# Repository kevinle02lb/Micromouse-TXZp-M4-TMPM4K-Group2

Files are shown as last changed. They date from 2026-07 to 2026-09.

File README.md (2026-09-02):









<div align="center">

# 🐭 Toshiba Micromouse

**Autonomous 16×16 Maze-Solving Robot**  
*Register-level firmware on Arm Cortex-M4*

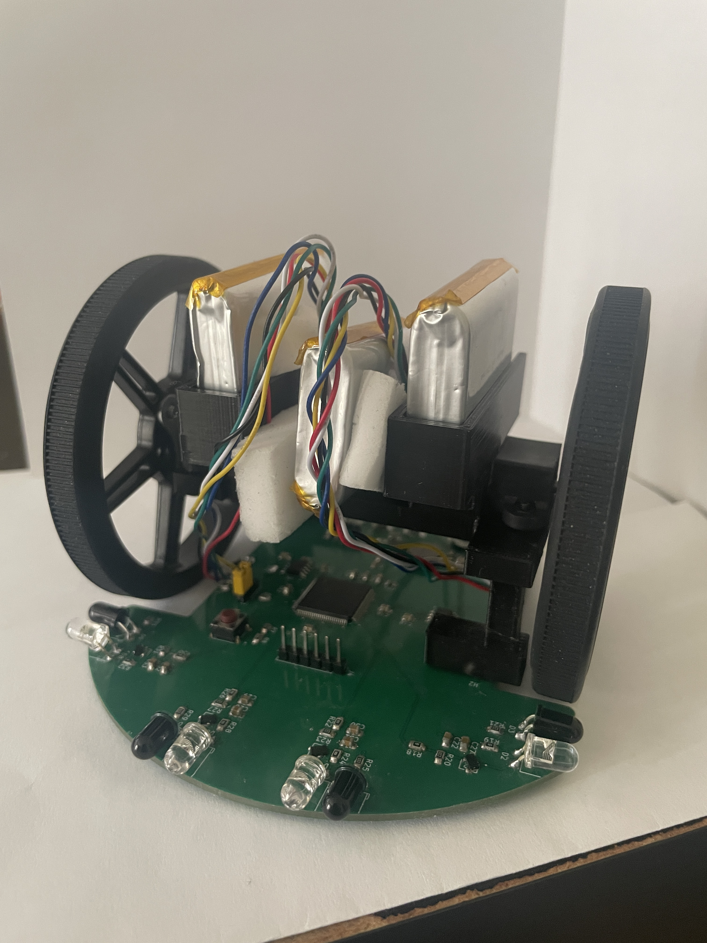
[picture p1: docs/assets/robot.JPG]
Micromouse


</div>

---

## Overview

Micromouse is a classic robotics competition: an autonomous palm-sized robot explores a 16×16 grid maze, maps the walls, & solves for the center.

This project implements the entire stack from scratch: custom 4-layer PCB, mechanical chassis, and register-level firmware, with no reliance on external HAL libraries.

---

## Platform

<div align="center">

Toshiba

### **Toshiba TMPM4KNF10AFG**, Arm Cortex-M4 with FPU

</div>

The TMPM4KNF10AFG comes from the **[M4K Group](https://toshiba.semicon-storage.com/us/semiconductor/product/microcontrollers/txz4aplus-series/m4k-group.html)** of Toshiba's **[TXZ+™4A Series](https://toshiba.semicon-storage.com/us/semiconductor/product/microcontrollers/txz4aplus-series.html)**, a line of 160 MHz Arm Cortex-M4 microcontrollers built for motor and inverter control. It pairs a fast floating-point core with dedicated on-chip hardware for driving motors, reading encoders, and sampling analog sensors. The same parts show up in BLDC/PMSM drives, HVAC compressors, power tools, and factory automation, and they carry IEC 60730 self-diagnosis support for appliance functional safety.

| Capability | Role in this build |
|---|---|
| Cortex-M4 @ 160 MHz + FPU | Navigation, PID, and flood-fill maze solving |
| On-chip motor & encoder hardware | Wheel feedback and PPG-generated motor PWM |
| High-speed analog sensing | IR wall detection |

Here the same silicon runs a much smaller problem: a 1 kHz driven by an interrupt and closed-loop PID over two brushed DC gear-motors. Dedicated hardware handles encoder counting and motor PWM, so the CPU stays free for navigation and flood-fill maze solving.

---

## Built With

<div align="center">

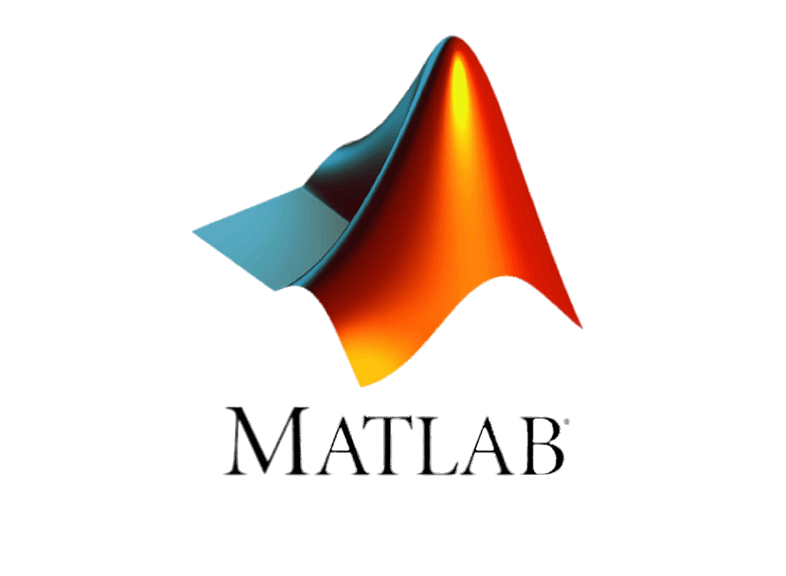
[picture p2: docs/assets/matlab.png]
MATLAB
| ARM | Keil µVision | KiCad | Fusion 360 | Git |  |
|:---:|:---:|:---:|:---:|:---:|:---:|
| **Arm Cortex-M4** | **Keil µVision** | **KiCad** | **Fusion 360** | **Git** | **MATLAB** |
| Register-level C | IDE / Build / Flash | 4-layer PCB | Chassis CAD | Version Control | Data Analysis |

</div>

## Gallery

<div align="center">

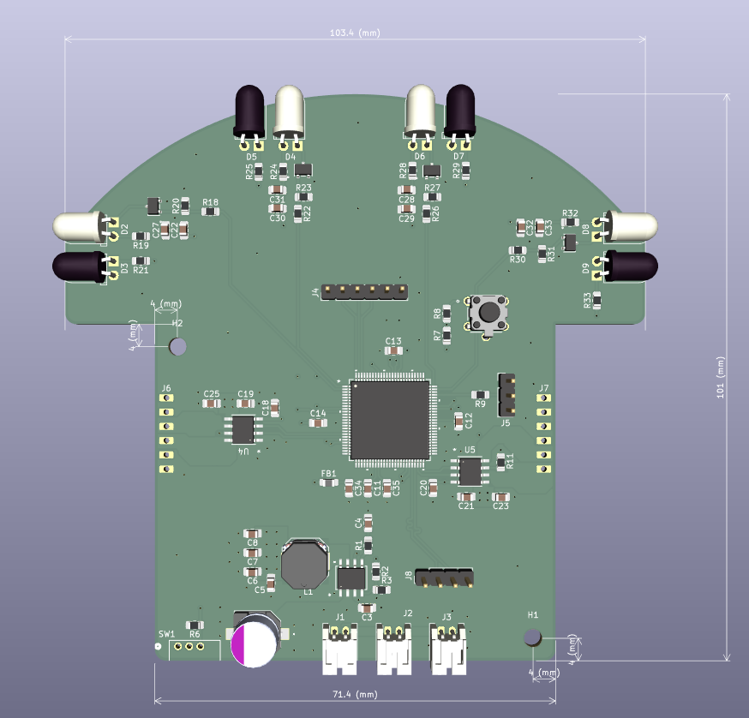
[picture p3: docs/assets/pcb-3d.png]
Custom PCB
 &nbsp;&nbsp;

*Custom PCB*

<br>

Fusion 360 Robot Render (Outdated Version)

*(Outdated Version) Fusion 360 render of the full mechanical assembly*

</div>

---

## Documentation
 
| Path | Contents |
|---|---|
| [`src/README.md`](src/README.md) | Firmware architecture, control loops, pin map, timer config |
| [`hardware/README.md`](hardware/README.md) | Hardware overview: chassis (Fusion) + PCB (KiCad) |
| [`hardware/pcb/README.md`](hardware/pcb/README.md) | Board specs, layout, schematic, component list |
| [`docs/README.md`](docs/README.md) | Docs index: assets, evidence, and analysis tooling |
| [`docs/evidence/README.md`](docs/evidence/README.md) | Module-test checklist and captured evidence |

---

## Quick Start

```text
IDE:     Keil µVision
Target:  TMPM4KNF10AFG (Arm Cortex-M4)
Debug:   CMSIS-DAP
Flash:   512 KB on-chip

```
[`Quick Start`](docs/README.md)

---

<div align="center">

**Kevin Le** &nbsp;•&nbsp; 2026 &nbsp;
</div>

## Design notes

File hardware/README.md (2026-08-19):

<div align="center">

# Hardware

**Physical design layer: mechanical + electrical**  
*3D-printed chassis in Fusion, custom control PCB in KiCad*

</div>

---

## Overview

The `hardware/` directory holds everything physical about the micromouse. The mechanical design, chassis and overall body, lives in Fusion. The electronics, a custom 4-layer control board, live in KiCad. Each has its own subfolder with its own design files.

---

## Structure

| Folder | Tool | Contents |
|---|---|---|
| [`fusion/`](fusion/) | Fusion | Chassis and mechanical model. STL for printing, STEP for CAD |
| [`pcb/`](pcb/) | KiCad | 4-layer control board. Schematic, layout, gerbers, BOM |

---

## Mechanical, Fusion

The chassis is designed in Fusion and 3D-printed. It carries the PCB, motors, and wheels, and defines the overall footprint of the mouse.

<!-- Add a render here once you have one, e.g.:
<div align="center">
<img src="../docs/assets/chassis-3d.png" width="480" alt="Chassis render">
</div>
-->

| Spec | Detail |
|---|---|
| Process | MJF (Multi Jet Fusion), via JLC3DP |
| Material | PA12-HP nylon |
| Finish | Dyed black (Optional) |
| Dimensions | 10.8 × 8.24 × 5.74 cm |
| Volume | 17.39 cm³ |

### Files

| File | Contents |
|---|---|
| [`fusion/chassis.stl`](fusion/chassis.stl) | Print-ready chassis mesh (STL) |
| [`fusion/Micromouse_v1.step`](fusion/Micromouse_v1.step) | Parametric mechanical model (STEP) |

---

## Drivetrain

Two encoder gearmotors driving 80 mm wheels, held to the chassis by N20 brackets.
The encoder feeds the odometry and speed loop in firmware.

### Motors

| Spec | Detail |
|---|---|
| Part | Pololu [#5211](https://www.pololu.com/product/5211) |
| Type | 30:1 Micro Metal Gearmotor HPCB 12V, side-connector encoder |
| Gear ratio | 29.86:1 (exact) |
| Encoder | 12 CPR quadrature on the motor shaft |
| No-load | 1100 RPM at 12 V, 80 mA |
| Stall | 0.39 kg&middot;cm, 0.75 A (theoretical) |
| Output shaft | 3 mm D, 9 mm long |
| Gearbox | 10 &times; 12 mm cross section (N20 form factor) |

Encoder cable is **not included**. It is a 6-pin JST SH-style, ordered separately.

### Wheels

| Spec | Detail |
|---|---|
| Part | Pololu [#3690](https://www.pololu.com/product/3690) |
| Type | Multi-Hub Wheel with inserts, black, 2-pack |
| Size | 80 &times; 10 mm, silicone tyre |
| Mounting | Collet insert, 3 mm D used here (3 mm round, 4 mm D, 4 mm round also supplied) |

The collet tightens as it compresses into the wheel disc, so it grips harder than
a press-fit wheel and is less likely to slip on the shaft.

### Brackets

Generic N20 motor brackets. Any pair sized for the 10 &times; 12 mm gearbox cross
section fits. No part number recorded, they are a commodity item.

### Firmware link

The encoder resolution at the gearbox output falls out of the two specs above:

```
12 CPR x 29.86 gear ratio = 358.3 counts per wheel revolution
```

That figure and the 80 mm wheel diameter set `COUNTS_PER_REV` and
`WHEEL_DIAMETER_MM` in [`Odometry.h`](../src/modules/Odometry.h). Both are
verified against the floor with `DRIVE_TEST` and `TURN_TEST`. See the
[test README](../src/README.md).

---

## Electrical, PCB

A custom 4-layer control board designed in KiCad, carrying the MCU, dual motor drivers, IR wall sensors, and the power and debug interface on a single micromouse-sized board.

| Spec | Detail |
|---|---|
| Layers | 4-layer |
| MCU | Toshiba TMPM4KNF10AFG (Cortex-M4F) |
| Motor drivers | 2 × TB67H450AFNG H-bridge |
| Sensing | 4 × IR emitter / receiver pairs |
| Battery | 3S LiPo, 11.1 V nominal |
| Logic supply | 5 V from a buck converter |

Full details, schematic, and design files are in the PCB README:

**→ [`pcb/README.md`](pcb/README.md)**

---

<div align="center">

[← Back to main README](../README.md)

</div>

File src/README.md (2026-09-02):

# 🐭 Toshiba Micromouse Firmware

```
    ╔══════════════════════════════════════════╗
    ║  ┌─────────┐    ┌─────────┐              ║
    ║  │  LEFT   │    │  RIGHT  │              ║
    ║  │  MOTOR  │    │  MOTOR  │              ║
    ║  │  T32A0  │    │  T32A3  │              ║
    ║  └────┬────┘    └────┬────┘              ║
    ║       │              │                   ║
    ║  ┌────┴──────────────┴────┐              ║
    ║  │    TMPM4KNF10AFG       │              ║
    ║  │    Cortex-M4 @ 160MHz  │              ║
    ║  │    ┌───────────────┐   │              ║
    ║  │    │  1kHz Control │   │              ║
    ║  │    │  Loop (T32A1) │   │              ║
    ║  │    └───────────────┘   │              ║
    ║  └────────────────────────┘              ║
    ║       │              │                   ║
    ║  ┌────┴────┐    ┌────┴────┐              ║
    ║  │  ENC0   │    │  ENC2   │              ║
    ║  │  Left   │    │  Right  │              ║
    ║  └─────────┘    └─────────┘              ║
    ╚══════════════════════════════════════════╝
```

---

## Architecture

Everything is driven by a single 1 kHz control tick. Each tick runs five stages
in order, and each stage consumes the output of the one above it. The maze
planner (`FloodFill`) is pure logic and never touches hardware. `Navigator` owns
all motion and calls the planner for decisions.

`Navigator` runs before `Motion` so the setpoint it produces is acted on within
the same tick rather than one tick late.

```
┌──────────────────────────────────────────────────────────────┐
│                          main.c                              │
│   while(1) {                                                 │
│     if (Timebase_GetAndClear()) {   ◄── 1 kHz tick           │
│       Encoder_Update();    // read encoders, filter speed    │
│       Odometry_Update();   // pose (x, y, heading)           │
│       IR_SampleStep();     // advance the IR sampler         │
│       Navigator_Update();  // plan/turn/drive FSM step       │
│       Motion_Update();     // PID -> motor PWM (non-blocking)│
│     }                                                        │
│   }                                                          │
└──────────────────────────┬───────────────────────────────────┘
                           │  once per tick
   ┌───────────┬───────────┼───────────┬────────────┐
   ▼           ▼           ▼           ▼            ▼
┌────────┐ ┌────────┐ ┌────────┐ ┌───────────┐ ┌──────────┐
│Encoder │ │Odometry│ │ Motion │ │ Navigator │ │ FloodFill│
│speed + │ │pose    │ │PID +   │ │ FSM:      │◄┤   BFS    │
│position│ │x,y,θ   │ │motor   │ │ plan→turn │ │ Algorithm│
└───┬────┘ └───┬────┘ └───┬────┘ │ →drive    │ └────┬─────┘
    │          │          │      └─────┬─────┘      │
    ▼          │          ▼            │            ▼
┌────────┐     │     ┌─────────┐       │       ┌──────────┐
│ENC0/2  │     │     │ Motor   │       │       │ IrSensor │
│A-ENC32 │     └────►│ TB67H450│       └──────►│ ADC      │
│quad in │           │ +T32A0/3│               │ 4× wall  │
└────────┘           │ PWM PPG │               │ sensing  │
                     └─────────┘               └──────────┘
```

**Control flow summary**

| Stage | Module | Role |
|---|---|---|
| 1 | `Encoder` | Read A-ENC32 counters(CPS) |
| 2 | `Odometry` | Integrate differential-drive pose from encoder deltas |
| 3 | `IrSensor` | Advance one phase of the ambient-cancelling sample cycle |
| 4 | `Navigator` | Non-blocking FSM. Asks `FloodFill` for moves, executes them |
| 5 | `Motion` | Per-wheel PID speed loop → `Motor` PWM duty |
| .. | `Profile` | Trapezoidal velocity profile. Called in `Navigator` |
| .. | `FloodFill` | Pure BFS planner over discovered walls (no hardware) |

---

## Project Structure

```
toshiba-micromouse/
├── keil/                     # Keil µVision project files
├── hardware/                 # Hardware overview for Mouse
├── docs/                     # Images and documentation assets
├── README.md                 # Project landing page
└── src/
    ├── README.md             # This file. Firmware architecture
    ├── main.c                # Entry point, 1 kHz control loop
    ├── ModuleTest.C          # Testing file 
    │
    ├── drivers/              # Register-level hardware layer
    │   ├── timer32A.c/h      # T32A: 20 kHz PWM (ch0/3) + 1 kHz tick (ch1)
    │   ├── gpio.c/h          # Port configuration + emitter GPIO
    │   ├── encoder32A.c/h    # A-ENC32 quadrature hardware read
    │   ├── adc.c/h           # ADC-I units A & C (IR receivers)
    │   ├── dma.c/h           # DMAC-B burst transfer for ADC (Optional)
    │   ├── uart.c/h          # UART-C serial debug output
    │   └── systick.c/h       # Blocking µs/ms delay (stateless)
    │
    └── modules/              # Application logic layer
        ├── Timebase.c/h      # 1 kHz tick flag service
        ├── Encoder.c/h       # Filtered speed + signed position
        ├── Odometry.c/h      # Differential-drive pose (x, y, θ)
        ├── PID.c/h           # Generic PID controller math
        ├── Motor.c/h         # TB67H450 H-bridge direction + duty
        ├── Motion.c/h        # PID speed loop bridging Encoder→Motor
        ├── Profile.c/h       # Trapezoidal velocity profile (mm, mm/s)
        ├── IrSensor.c/h      # IR sampling, ambient cancel, distance
        ├── FloodFill.c/h     # BFS flood-fill maze planner
        └── Navigator.c/h     # Cell-level motion sequencer (FSM)
```

---

## Hardware Specs

| Component | Part | Interface |
|---|---|---|
| **MCU** | TMPM4KNF10AFG | Arm Cortex-M4, 160 MHz, 5 V |
| **Motors** | TB67H450AFNG + Pololu #5211 N20 30:1 | T32A PPG PWM @ 20 kHz |
| **Encoders** | A-ENC32 (on-chip) | Quadrature, 12 CPR × 29.89 ≈ 359/rev |
| **IR Sensors** | IR LED + phototransistor ×4 | ADC-I |
| **Debug** | CMSIS-DAP + Level Shifter (TXB0104) | SWD |

### Pin Map

```
    ┌─────────────────────────────────────────────┐
    │  PORT A  │ PA3  ──► T32A00OUTA  (Left PWM)  │
    │          │ PA4  ──► T32A00OUTB  (Left PWM)  │
    ├─────────────────────────────────────────────┤
    │  PORT C  │ PC2  ──► T32A30OUTA  (Right PWM) │
    │          │ PC3  ──► T32A30OUTB  (Right PWM) │
    ├─────────────────────────────────────────────┤
    │  PORT N  │ PN0  ──► ENC0A  (Left encoder)   │
    │          │ PN1  ──► ENC0B  (Left encoder)   │
    ├─────────────────────────────────────────────┤
    │  PORT D  │ PD3  ──► ENC2A  (Right encoder)  │
    │          │ PD4  ──► ENC2B  (Right encoder)  │
    ├─────────────────────────────────────────────┤
    │  PORT L  │ PL0  ──► AINA16  (Far Left IR)   │
    │          │ PL1  ──► AINA15  (Left IR)       │
    ├─────────────────────────────────────────────┤
    │  PORT J  │ PJ0  ──► AINC00  (Far Right IR)  │
    │          │ PJ1  ──► AINC01  (Right IR)      │
    ├─────────────────────────────────────────────┤
    │  PORT U  │ PU0  ──► Left IR Emitter         │
    │          │ PU1  ──► Far Left IR Emitter     │
    ├─────────────────────────────────────────────┤
    │  PORT G  │ PG4  ──► Far Right IR Emitter    │
    │          │ PG5  ──► Right IR Emitter        │
    └─────────────────────────────────────────────┘
```

---

## Timer Configuration

```
┌──────────────────────────────────────────────────────────────┐
│  T32A0 (Left Motor)     │  T32A3 (Right Motor)               │
│  ─────────────────────  │  ─────────────────────             │
│  Mode:     16-bit PPG   │  Mode:     16-bit PPG              │
│  Prescaler: 1:1         │  Prescaler: 1:1                    │
│  Frequency: 20 kHz      │  Frequency: 20 kHz                 │
│  Period:   4000 counts  │  Period:   4000 counts             │
│  Pins:     PA3, PA4     │  Pins:     PC2, PC3                │
│  Duty:     RG0 = 0-4000 │  Duty:     RG0 = 0-4000            │
├──────────────────────────────────────────────────────────────┤
│  T32A1 (Control Loop)                                        │
│  ─────────────────────                                       │
│  Mode:     32-bit Interval                                   │
│  Prescaler: 1:1                                              │
│  Frequency: 1 kHz                                            │
│  Period:   80000 counts  (80 MHz ΦT0)                        │
│  Interrupt: INTT32A01AC (NVIC)                               │
│  Flag:     T32A01AC_IRQ_Fire (volatile bool)                 │
└──────────────────────────────────────────────────────────────┘
```

---

## Navigation Model

`FloodFill` and `Navigator` use **relative** moves at their boundary, so only
one of them needs a compass.

- `FloodFill_Plan()` returns one of `FORWARD`, `TURN_LEFT`, `TURN_RIGHT`,
  `TURN_AROUND`, `STOP`. It owns the grid cell and heading, and it is the only
  module that does.
- `Navigator` holds **no heading**. Every move is a *segment*, a fixed length of
  wheel path measured from encoder positions latched at segment start.
- Odometry is not read by `Navigator` at all. It uses `Odometry.h` for the
  geometry constants and nothing else.

**Segments**

| Type | Wheels | Length |
|---|---|---|
| Drive | both forward | `CELL_SIZE_MM` |
| Turn | opposed | `θ × WHEELBASE_MM / 2` per wheel |

A pivot is an arc, so it is a straight-line profile in disguise. One `Profile`
serves both, which is why there is no separate angular controller.

**FSM**

```
NAV_PLAN → NAV_TURN → NAV_DRIVE → NAV_SETTLE → NAV_PLAN
    ↓
NAV_FINISHED
```

`NAV_TURN` is skipped when the action is `FORWARD`. `NAV_SETTLE` holds the robot
still so the IR filter converges on the cell it stopped in before `NAV_PLAN`
reads walls from it.

**Correction**

Dead reckoning drifts, so the maze walls are the absolute reference.

- Side IR keeps the robot centred in a corridor, damped by encoder skew
- Front IR resets distance error at any cell facing a wall
- Both fall back to encoder-only when no wall is in range

> **Invariant (load-bearing):** `FloodFill`'s direction enum must stay clockwise
> (N=0, E=1, S=2, W=3). `Dir_Right()` is `(dir + 1) & 3`. Renumbering it breaks
> every turn.

---

## Call Graphs

Generated with [Doxygen](https://www.doxygen.nl/) and rendered by
[Graphviz](https://graphviz.org/). Doxygen parses the source comments and emits
the browsable API docs; Graphviz draws the call and caller graphs.

Full documentation, with every function, its callers, and cross-referenced
source, opens at:

**[`docs/doxygen/html/index.html`](../docs/doxygen/html/index.html)**

Regenerate after changing the source:

```
doxygen Doxyfile
```

**`main()`**

main call graph

**`Navigator_Update()`**

Navigator_Update call graph

The graph shows every call the function can make, not which state makes it.
The FSM order is in [Navigation Model](#navigation-model).

---

## Build & Flash

```text
IDE:     Keil µVision
Target:  TMPM4KNF10AFG
Debug:   CMSIS-DAP
Flash:   On-chip 512 KB
```

---

## Deployment Calibration

Before real runs, these must be measured/tuned on the actual robot:

| Where | What | Why |
|---|---|-----|
| `Encoder` | Forward → **increasing** position | Reversed sign turns PID into positive feedback (runaway) |
| `Odometry.h` | `WHEEL_DIAMETER_MM`, `COUNTS_PER_REV` | Sets `MM_PER_COUNT`. Wrong value scales every distance |
| `Odometry.h` | `WHEELBASE_MM` | Sets the arc length of a turn. Wrong value over or under rotates |
| `IrSensor.c` | `ir_cal[]` ADC→distance points | One table per channel. Wall detection and wall following both read it |
| `Navigator.c` | `IR_SIDE_TARGET_MM` | Side reading when centred. Only used when one wall is visible |
| `Navigator.c` | `IR_FRONT_TARGET_MM` | Front reading at a cell centre. Sets where a drive stops against a wall |
| `PID.h` | Gains for CPS-scaled error | Error is ~thousands (CPS); default `Kp` saturates instantly |

Angle depends on the *ratio* `MM_PER_COUNT / WHEELBASE_MM`, distance on
`MM_PER_COUNT` alone. Change the wheel and the wheelbase has to move with it or
every turn shifts by the same percentage.

Which test measures each value, and whether it has been done, is tracked in
[`docs/evidence/README.md`](../docs/evidence/README.md).

---

## Module Status

| Module | Status | Description |
|---|---|---|
| `Timebase` | Done | 1 kHz control tick flag |
| `Encoder` | Done | Filtered speed + signed position |
| `Odometry` | Done | Differential-drive pose estimate |
| `PID` | Done | Generic PID controller |
| `Motor` | Done | H-bridge direction + duty |
| `Motion` | Done | PID speed loop (Encoder→Motor) |
| `Profile` | Done | Trapezoidal velocity profile |
| `IrSensor` | Done | IR sampling, ambient cancel, distance |
| `UART` | Done | Serial debug output (TX) |
| `FloodFill` | Done | BFS flood-fill planner |
| `Navigator` | Done | Segment FSM + wall following |

---

## References

- [TMPM4KNF10AFG Product Page](https://toshiba.semicon-storage.com/us/semiconductor/product/microcontrollers/txz4aplus-series/m4k-group.html)
- [RM-T32A-C Timer Reference](https://toshiba.semicon-storage.com/info/RM-T32A-C_en_20241129.pdf)
- [RM-A-ENC32-A Encoder Reference](https://toshiba.semicon-storage.com/info/RM-A-ENC32-A_en_20250221.pdf)
- [RM-ADC-I Reference](https://toshiba.semicon-storage.com/info/RM-ADC-I_en_20251205.pdf)
- [RM-DMAC-B DMA Reference](https://toshiba.semicon-storage.com/info/RM-DMAC-B_en_20241031.pdf)
- [Pololu #5211 Motor Datasheet](https://www.pololu.com/file/0J1487/pololu-micro-metal-gearmotors-rev-6-2.pdf)
- [Doxygen](https://www.doxygen.nl/) by Dimitri van Heesch, GPL-2.0
- [Graphviz](https://graphviz.org/), EPL-1.0

---

**Author:** Kevin Le &nbsp;•&nbsp; 2026

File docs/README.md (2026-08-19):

# Documentation

Reference material, test evidence, setup notes, and analysis tooling for the
Toshiba micromouse.

## Contents

| Folder | Contents |
|---|---|
| [`assets/`](assets/) | Images used across the docs — diagrams, photos, screenshots. |
| [`evidence/`](evidence/) | Module-testing evidence: a per-module checklist plus captured serial logs and videos. |
| [`matlab/`](matlab/) | Analysis scripts. `plot_pid.m` plots UART telemetry (setpoint vs. actual speed and controller output) for PID tuning. |

## Conventions

- Images referenced by any README live in `assets/` and are linked with a relative path.
- Test recordings and captured serial logs go in `evidence/`, one per module test.
- Analysis scripts read the comma-separated telemetry streamed by the firmware test harness (`ModuleTest.c`).

---

## Quick start

### 1. Install Keil MDK-ARM

uVision plus the Arm compiler. The free Community edition is enough for this
project's code size.

### 2. Add the device pack

Pack Installer &rarr; search `TMPM4K` &rarr; install the Toshiba M4K device family pack.

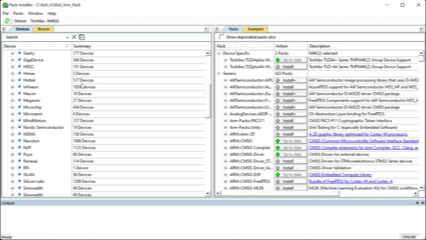
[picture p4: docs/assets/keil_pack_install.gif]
Pack Installer


> **The pack ships Arm Compiler 5 project files only.** uVision defaults to
> Arm Compiler 6, and an AC5 project will not build against it.

### 3. Get the Toshiba peripheral sample

Download `TMPM4KyA_common_sample_v2.2.0.zip` from the
[M4K sample software page](https://toshiba.semicon-storage.com/us/semiconductor/product/microcontrollers/software-library/txzplus-m4k-group.html)
(*Peripheral Sample Software* section). These project files **do** support Arm
Compiler 6 — use them as the base rather than the pack's.

The samples also map onto the drivers in this project:

| Sample | Driver here |
|---|---|
| `A_ENC32` | `drivers/encoder32A.c` |
| `T32A` | `drivers/timer32A.c` — PWM and the 1 kHz tick |
| `ADC` | `drivers/adc.c` — IR receivers |
| `UART` | `drivers/uart.c` — telemetry |
| `PORT` | `drivers/gpio.c` — IR emitters |

### 4. Pick which `main()` builds

There are two: `main.c` (the robot) and `ModuleTest.c` (the test harness).
Building both gives a linker error:

```
L6200E: Symbol main multiply defined
```

In the Project pane, right-click the file you do **not** want &rarr;
*Options for File* &rarr; untick **Include in Target Build**.

| Goal | Build | Exclude |
|---|---|---|
| Run the maze | `main.c` | `ModuleTest.c` |
| Run a module test | `ModuleTest.c` | `main.c` |

For a module test, also uncomment exactly one `#define` at the top of
`ModuleTest.c`. See the [test README](../src/README.md).

### 5. Connect the debugger

| Item | Detail |
|---|---|
| Probe | External CMSIS-DAP |
| Level shifter | TXB0104 between probe and target |
| Target supply | 5 V &mdash; **required**, the ADC does not work below it |

See PCB README.md for more details.

Options for Target &rarr; Debug &rarr; select CMSIS-DAP, then Settings and confirm the
device is detected before flashing.

### 6. Build and flash

`F7` to build, `F8` to download.

### 7. Open a serial terminal

Telemetry streams as comma-separated text.

| Setting | Value |
|---|---|
| Baud | 115200 |
| Format | 8-N-1 |
| Flow control | none |

TeraTerm or PuTTY both work. Log to file if you want to plot the run with
`matlab/plot_pid.m`.

## Troubleshooting

| Symptom | Cause |
|---|---|
| `L6200E: Symbol main multiply defined` | Both `main.c` and `ModuleTest.c` in the build — see step 4 |
| Compiler errors in Toshiba headers | AC5 project files under AC6 — see step 3 |
| ADC reads zero or noise | Target not at 5 V |
| No serial output | Wrong COM port, or `UART_Init()` not called for the active test |

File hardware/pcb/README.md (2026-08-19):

<div align="center">

# Micromouse PCB

**Custom 4-Layer Control Board**  
*Integrated MCU, motor drivers, and IR sensing*

PCB 3D render

</div>

---

## Overview

The mainboard is a custom 4-layer PCB designed in KiCad that carries the full electronics stack on a single micromouse-sized board: the microcontroller, dual motor drivers, four IR wall sensors, and the power and debug interface.

---

## Board Specs

| Spec | Detail |
|---|---|
| Layers | 4-layer |
| MCU | Toshiba TMPM4KNF10AFG (Cortex-M4F) |
| Motor drivers | 2 × TB67H450AFNG H-bridge |
| Sensing | 4 × IR emitter / receiver pairs |
| Debug | CMSIS-DAP (SWD) via TXB0104 level shifter |
| Battery | 3S LiPo, 11.1 V nominal |
| Logic supply | 5 V from a buck converter |

---

## Power

| Rail | Voltage | Source |
|---|---|---|
| Battery | 11.1 V (3S LiPo) | Pack |
| Motor | 11.1 V | Direct from pack |
| Logic | 5 V | Buck converter |

Motors are the 12 V variant, so they run straight off the pack. Buck rather than
LDO because 11.1 V down to 5 V is too big a drop to burn as heat.

---

## Layout

<div align="center">

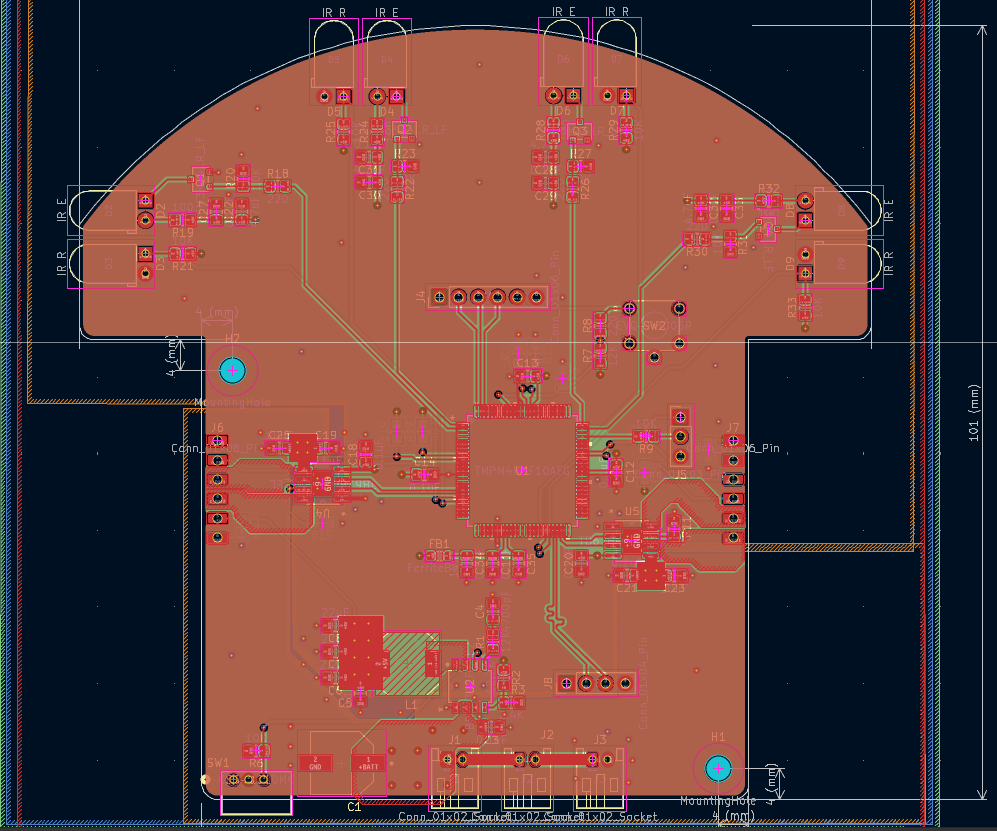
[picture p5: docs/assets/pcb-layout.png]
PCB layout


*Copper layers and component placement*

</div>

---

## Key Components

| Component | Part | Role |
|---|---|---|
| MCU | TMPM4KNF10AFG | Cortex-M4F, control & sensing |
| Motor driver | TB67H450AFNG ×2 | Brushed DC H-bridge, PWM speed control |
| Motors | Pololu #5211 N20 30:1 | Drive, with quadrature encoders |
| IR sensing | IR LED + phototransistor ×4 | Wall detection via ADC |
| Level shifter | TXB0104 | 5 V ↔ 3.3 V for SWD debug |

---

## Bench Setup

External equipment used for programming and debug:

<div align="center">

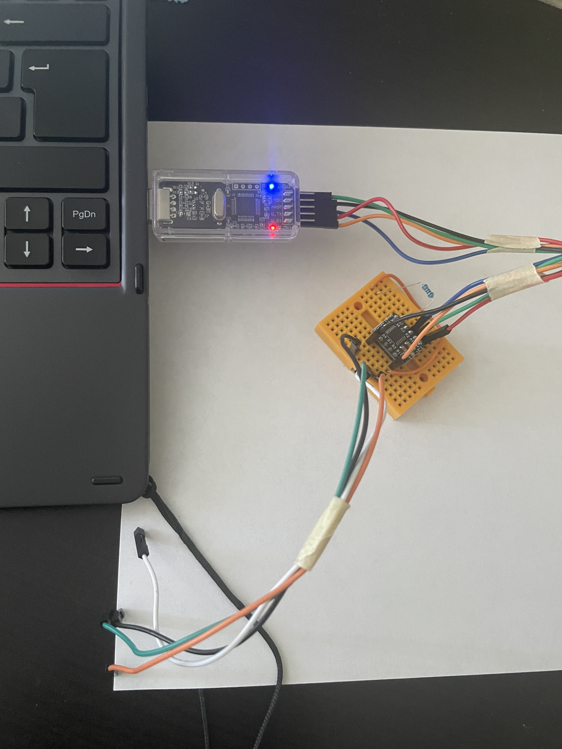
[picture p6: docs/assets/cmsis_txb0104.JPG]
SWD debug setup
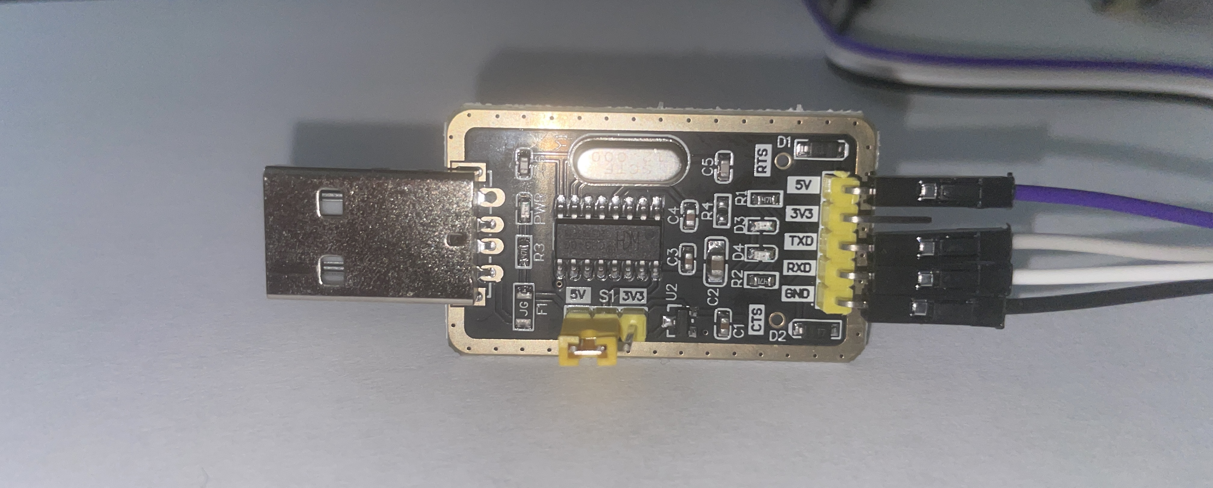
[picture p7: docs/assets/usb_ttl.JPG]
USB-UART converter
 &nbsp;&nbsp; 

*SWD debug via level shifter, and USB-UART for serial logging*

</div>

| Equipment | Purpose |
|---|---|
| CMSIS-DAP probe | SWD programming & debug |
| Logic level shifter | 5 V ↔ 3.3 V for the SWD lines |
| USB-UART converter | Serial console (115200 8-N-1) over the CH340G/debug UART |

Note: TXB0104 OE has a Pull-up. Recommended: 10k - 50k Ohms 

---

## Redesign Notes

Ideas for anyone rebuilding this board, roughly ordered by how much they save.

### Drop to 2 layers

The 4-layer stackup buys a solid ground plane and easy routing. A 2-layer board
runs about half the price at most fabs, and the component count here is low
enough to make it workable. Plan the ground pour carefully around the ADC inputs
if you do.

### Use a 64-pin MCU

The M4K group ships in packages from 64 to 100 pins. This build uses roughly
twenty. A smaller package costs less and frees board area, which is the other
half of shrinking the board.

### Remove the encoder pull-ups

The Pololu encoder board already pulls channels A and B to Vcc through 10 kΩ.
On-board pull-ups parallel those down to 5 kΩ, which works but does nothing
useful. Four resistors saved.

### Hardwire BOOT_N

The bridge connector only matters if you need the built-in serial bootloader.
With SWD programming it never moves, so a 10 kΩ pull-up in its place removes a
connector and an assembly step.

Trade-off: the bootloader is your recovery path if the SWD pins ever get
misconfigured. Losing it means a bad flash is harder to walk back.

### 6 V motors and an LDO

Pololu's 6 V and 12 V HPCB motors perform identically at their own rated
voltages. The 6 V version just draws twice the current. That opens up a 2S pack
with an LDO, dropping 2.4 V instead of 6.1 V, and an LDO is one part rather than
a controller, an inductor, and a capacitor bank.

Trade-off: double the motor current through the H-bridges, and the LDO still runs
warmer than a buck. Cheaper and simpler, not better.

### One dual-channel motor driver

Two single H-bridges could be one dual package. Fewer parts, less area, lower
cost. Check the voltage rating against your pack first, plenty of common dual
drivers top out below a charged 3S.

---

## Schematic

The full schematic is available as a PDF:

[View schematic (PDF)](Schematic.pdf)

---

## Design Files

| File | Contents |
|---|---|
| [`TMPM4KNF10AFG.kicad_sch`](Kicad/TMPM4KNF10AFG.kicad_sch) | Schematic source (KiCad) |
| [`TMPM4KNF10AFG.kicad_pcb`](Kicad/TMPM4KNF10AFG.kicad_pcb) | Board layout source (KiCad) |
| [`Schematic.pdf`](Schematic.pdf) | Rendered schematic |
| [`board.step`](board.step) | 3D board model (STEP) |
| [`BOM.csv`](BOM.csv) | Bill of materials |
| [`gerber/`](gerber/) | Fabrication outputs |

---

<div align="center">

[← Back to hardware README](../README.md)

</div>

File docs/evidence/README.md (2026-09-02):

# Module Testing

Each test is a `#define` at the top of `ModuleTest.c`. Uncomment one, build, run.
One at a time. Work down the table — later tests assume earlier ones pass.

**Status:** &#9744; pending &nbsp;|&nbsp; &#128260; in progress &nbsp;|&nbsp; &#9989; pass &nbsp;|&nbsp; &#10060; fail

| # | Define | Proves | Pass criteria | Status | Evidence |
|---|---|---|---|:---:|---|
| 1 | `IR_EMITTER_TEST` | Emitters drive | All four light in the counter pattern | &#9989;  | "evidence\01_IR_EMITTER_TEST.mp4" |
| 2 | `MOTOR_TEST` | Direction and duty per wheel | 18 phases match the table comment; `test_enc_left` rises on FORWARD, falls on REVERSE | &#9989; | "evidence\02_MOTOR_TEST.mp4" |
| 3 | `IR_TEST` | Channels respond to a wall | `FL L R FR` rise as a wall nears, fall when removed | &#9989; | "evidence\03_IR_TEST.mp4" |
| 4 | `MOTION_TEST` | Speed loop tracks a setpoint | `pvL`/`pvR` converge on `sp` | &#9989; | "evidence\04_MOTION_500CPS.mp4", "evidence\04_MOTION_1000CPS.pdf, "evidence\04_MOTION_1000CPS.txt"|
| 5 | `ODOM_TEST` | Pose maths, encoder signs | Pushed straight: `encL ≈ encR`, `deg ≈ 0`. Rotated CCW: `deg` rises, `diff` positive | &#9989; | "evidence\05_ODOM_TEST.mp4" |
| 6 | `DRIVE_TEST` | Distance calibrated | Final `dist` matches a ruler within 2 mm | &#9989; | "evidence\06_DRIVE.mp4" , "evidence\06_DRIVE.txt"|
| 7 | `TURN_TEST` | Angle calibrated | Final `arc` reaches `target`; protractor reads 90&deg; | &#9989; | "evidence\07_TURN_TEST.mp4" , "evidence\07_TURN_DATA.txt" |
| 8 | Full run (`main.c`) | Robot solves the maze | Reaches the 2&times;2 goal | &#9989; | "evidence\08_MAIN_TEST.mp4" |

## Watch out

`deg` is computed from `arc` by a fixed constant, and `dist` from the encoder
count. Neither can disagree with itself. **A ruler or protractor is the only
real check on tests 6 and 7.**

In the last rows of either, `sp` should taper toward zero. If it stops at the
speed floor instead, the wheels are still moving when the segment ends.

## Evidence

Photo or clip is fine — no write-up needed. Drop it in `evidence/` and link it
from the table.

Keep the raw serial log next to any plot so a run can be re-plotted.

## Calibration

Values live in the code, not here. Re-run the test if the hardware changes.

- `WHEEL_DIAMETER_MM`, `COUNTS_PER_REV` (`Odometry.h`) &rarr; `DRIVE_TEST`
- `WHEELBASE_MM` (`Odometry.h`) &rarr; `TURN_TEST`
- `ir_cal[][]`, `IR_SIDE_TARGET_MM`, `IR_FRONT_TARGET_MM` &rarr; `IR_TEST`

## Notes

-

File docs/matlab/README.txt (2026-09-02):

MATLAB PID TELEMETRY TOOLS
==========================

Two scripts read the comma separated stream emitted by MotionTest_StreamRow
in ModuleTest.c. Both expect the MOTION_TEST header:

    sp,pvL,pvR,mvL,mvR

    sp    setpoint, counts per second
    pvL   left wheel speed, counts per second
    pvR   right wheel speed, counts per second
    mvL   left PID output, percent duty, range -100 to 100
    mvR   right PID output, percent duty, range -100 to 100

Link settings, fixed by UART_Init in uart.c:

    115200 Bd, 8 data bits, no parity, 1 stop bit, no flow control
    line terminator CR then LF

FILES
-----

capture_pid.m   Reads the UART directly, writes a CSV, plots while capturing.
plot_pid.m      Reads a saved file and plots it. No serial port involved.

CHOOSING BETWEEN THEM
---------------------

capture_pid.m   Use during tuning. One step from robot to plot.
plot_pid.m      Use to review a run already saved, or a TeraTerm capture.

A COM port allows one program at a time. TeraTerm and capture_pid.m cannot
both hold it. Close TeraTerm before running capture_pid.m.

CAPTURE_PID.M
-------------

Settings at the top of the file:

    line  7   port          serial port name
    line  8   duration_s    capture length in seconds
    line  9   print_every   must match MOTION_TEST_PRINT_EVERY in firmware
    line 10   loop_hz       control loop rate, 1000

Steps:

    1.  Put blocks under the robot. Wheels off the ground. MotionTest_Run
        commands 250 CPS before entering its loop, so the wheels turn as
        soon as the board boots.
    2.  Flash the MOTION_TEST build in Keil.
    3.  Plug in the USB serial cable.
    4.  Close TeraTerm if it is open.
    5.  Open capture_pid.m in MATLAB.
    6.  In the Command Window, run:  serialportlist
    7.  Set port on line 7 to the port from step 6. Save.
    8.  Press Run.
    9.  Wait for the Command Window to print:
            Waiting for the header row, press RESET on the robot.
    10. Press RESET on the robot.
    11. Wait for the capture to finish. The Command Window prints the row
        count and the CSV filename.

Step 10 must come after step 9. The firmware prints the header once at
boot, so MATLAB has to be listening before the board starts.

Output file:

    pidlog_YYYYMMDD_HHMMSS.csv

Written row by row during the capture, so an interrupted run still leaves a
readable file. The format is the input format plot_pid.m reads.

PLOT_PID.M
----------

Settings at the top of the file:

    line  5   file          path to the log
    line  6   print_every   must match MOTION_TEST_PRINT_EVERY in firmware
    line  7   loop_hz       control loop rate, 1000

Steps:

    1.  Set file on line 5 to the log to plot. This accepts a CSV from
        capture_pid.m or a TeraTerm text capture.
    2.  Press Run.

Capturing with TeraTerm instead of capture_pid.m:

    File > Log, "Plain text" on, "Timestamp" off.

Timestamps left on prepend text to every line, which makes the rows
non numeric and produces an empty plot.

OUTPUT COMMON TO BOTH
---------------------

Upper axis   setpoint against left and right wheel speed
Lower axis   left and right controller output, with saturation at +/-100
             marked by dotted lines

The two axes share their time axis, so zooming one zooms the other.

The Command Window prints steady state figures over the last 20 percent of
the run: mean setpoint, mean speed and error per side, mean output per side,
and peak overshoot per side.

READING THE RESULT
------------------

Steady state error non zero and equal on both sides
    Integral gain too low, or the deadzone compensation is short.

One side settles at a different speed than the other
    Mechanical or per wheel calibration difference, not a gain problem.

Output pinned at +100 or -100 for long stretches
    The controller is saturated. Gains beyond that point have no effect.

Overshoot with visible ringing
    Proportional gain too high for the current derivative gain.

TROUBLESHOOTING
---------------

Port COM5 is unavailable
    Another program holds the port. Close TeraTerm.

No data on COM5
    Wrong port, cable not connected, or RESET was not pressed. Repeat from
    step 6.

Script sits at "Waiting for the header row" and never proceeds
    The board was already streaming before MATLAB opened the port, so the
    header had already gone out. Press Ctrl-C in the Command Window, then
    repeat from step 8.

Header is "...", expected "sp,pvL,pvR,mvL,mvR"
    A different test build is flashed. Rebuild with MOTION_TEST defined.

Plot appears but the time axis is wrong
    print_every does not match MOTION_TEST_PRINT_EVERY in ModuleTest.c.

MATLAB reports the port is in use after an error
    capture_pid.m releases the port through onCleanup, including on Ctrl-C.
    If a port is still held after a crash, run:  clear all

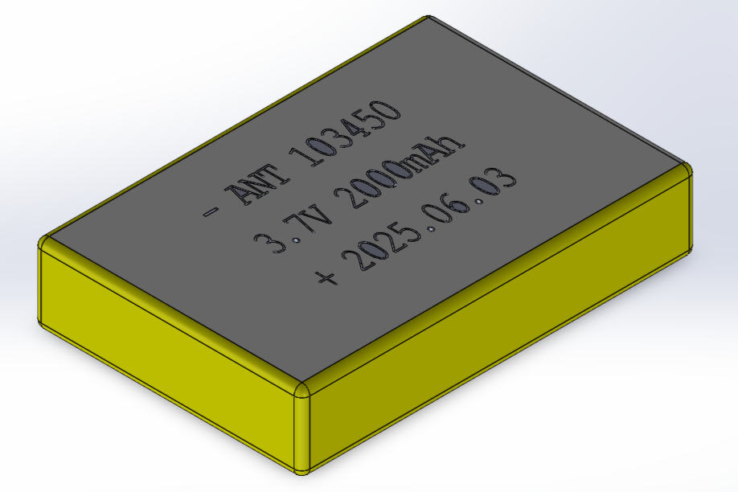
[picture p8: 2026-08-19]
hardware/fusion/lithium-polymer-battery-103450-2000mah-1.snapshot.2/LiPo_103450_2000mAh.png

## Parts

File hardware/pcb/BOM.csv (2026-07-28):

Reference | Qty | Value | DNP | Exclude from BOM | Exclude from Board | Footprint | Datasheet
U4,U5 | 2 | TB67H450AFNG_EL |  |  |  | TB67H450AFNG:P-HSOP8-0405-1.27-002_TOS | TB67H450AFNG_EL
U2 | 1 | BD9C301FJ-E2 |  |  |  | BD9C301FJ:SOP-J8_ROM | https://fscdn.rohm.com/en/products/databook/datasheet/ic/power/switching_regulator/bd9c301fj-e.pdf
U1 | 1 | TMPM4KNF10AFG |  |  |  | TMPM4KNF10AFG:P-LQFP100-1414-0p50-002_TOS | TMPM4KNF10AFG
SW2 | 1 | EVQ-PBG05R |  |  |  | EVQ-PBG05R:EVQ-PBG05R_PAN | EVQ-PBG05R
SW1 | 1 | CSS-1210MC |  |  |  | CSS-1210MC:SW3_CSS-1210MC_NDC | CSS-1210MC
R19,R24,R28,R32 | 4 | 100 |  |  |  | Resistor_SMD:R_0805_2012Metric_Pad1.20x1.40mm_HandSolder
R10,R11 | 2 | 0.22 |  |  |  | Resistor_SMD:R_0805_2012Metric_Pad1.20x1.40mm_HandSolder
R6,R9,R14,R15,R16,R17,R20,R21,R23,R25,R27,R29,R31,R33 | 14 | 10K |  |  |  | Resistor_SMD:R_0805_2012Metric_Pad1.20x1.40mm_HandSolder | https://industrial.panasonic.com/cdbs/www-data/pdf/RDM0000/AOA0000C307.pdf
R5,R8,R18,R22,R26,R30 | 6 | 220 |  |  |  | Resistor_SMD:R_0805_2012Metric_Pad1.20x1.40mm_HandSolder | https://industrial.panasonic.com/cdbs/www-data/pdf/RDM0000/AOA0000C307.pdf
R4 | 1 | 1K |  |  |  | Resistor_SMD:R_0805_2012Metric_Pad1.20x1.40mm_HandSolder
R3 | 1 | 2.4K |  |  |  | Resistor_SMD:R_0805_2012Metric_Pad1.20x1.40mm_HandSolder
R2 | 1 | 12.7K |  |  |  | Resistor_SMD:R_0805_2012Metric_Pad1.20x1.40mm_HandSolder
R1,R7 | 2 | 12K |  |  |  | Resistor_SMD:R_0805_2012Metric_Pad1.20x1.40mm_HandSolder
Q1,Q2,Q3,Q4,Q5 | 5 | NMOS |  |  |  | SSM3K324R,LF:SOT-23F_TOS-M | https://toshiba.semicon-storage.com/info/SSM3K324R_datasheet_en_20250130.pdf?did=13879&prodName=SSM3K324R
L1 | 1 | 4.7uH |  |  |  | 1217AS-H-4R7N=P3:IND_1217AS-H-4R7N=P3 | https://www.murata.com/~/media/webrenewal/products/inductor/chip/tokoproducts/wirewoundferritetypeforpl/m_dem8045c.ashx
J8 | 1 | Conn_01x04_Pin |  |  |  | Connector_PinHeader_2.54mm:PinHeader_1x04_P2.54mm_Vertical
J6,J7 | 2 | Conn_01x06_Pin |  |  |  | Library:PAD_01x06_2.54mm
J5 | 1 | Conn_01x03_Pin |  |  |  | Connector_PinHeader_2.54mm:PinHeader_1x03_P2.54mm_Vertical
J4 | 1 | Conn_01x06_Pin |  |  |  | Connector_PinHeader_2.54mm:PinHeader_1x06_P2.54mm_Vertical
J1,J2,J3 | 3 | Conn_01x02_Socket |  |  |  | Connector_JST:JST_PH_S2B-PH-K_1x02_P2.00mm_Horizontal
FB1 | 1 | FerriteBead |  |  |  | Inductor_SMD:L_0805_2012Metric_Pad1.05x1.20mm_HandSolder | https://pim.murata.com/asset/pim4/ferriteBeadInductortypefilter/ENFA0005_PDF_FERRITEBEADINDUCTORTYPEFILTER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
D3,D5,D7,D9 | 4 | IR R |  |  |  | LED_THT:LED_D5.0mm_Horizontal_O1.27mm_Z3.0mm_IRBlack
D2,D4,D6,D8 | 4 | IR E |  |  |  | LED_THT:LED_D5.0mm_Horizontal_O1.27mm_Z3.0mm_Clear
D1 | 1 | CRZ10 | DNP |  |  | Diode_SMD:D_SOD-123F | https://toshiba.semicon-storage.com/info/CRY68_datasheet_en_20141010.pdf?did=3175&prodName=CRY68
C23,C25,C34 | 3 | 10uF |  |  |  | Capacitor_SMD:C_0805_2012Metric_Pad1.18x1.45mm_HandSolder | https://search.murata.co.jp/Ceramy/image/img/A01X/G101/ENG/GRM21BZ71E106KE15-01.pdf
C9,C10,C22,C28,C30,C32 | 6 | 4.7uF |  |  |  | Capacitor_SMD:C_0805_2012Metric_Pad1.18x1.45mm_HandSolder
C7,C8 | 2 | 22uF |  |  |  | Capacitor_SMD:C_0805_2012Metric_Pad1.18x1.45mm_HandSolder | https://search.murata.co.jp/Ceramy/image/img/A01X/G101/ENG/GRM21BZ71A226ME15-01.pdf
C6 | 1 | 2.2uF |  |  |  | Capacitor_SMD:C_0805_2012Metric_Pad1.18x1.45mm_HandSolder | https://search.murata.co.jp/Ceramy/image/img/A01X/G101/ENG/GRM21BR71E225KE11-01.pdf
C4 | 1 | 4700pF |  |  |  | Capacitor_SMD:C_0805_2012Metric_Pad1.18x1.45mm_HandSolder
C3,C5,C11,C12,C13,C14,C17,C18,C19,C20,C21,C24,C26,C27,C29,C31,C33,C35 | 18 | 0.1uF |  |  |  | Capacitor_SMD:C_0805_2012Metric_Pad1.18x1.45mm_HandSolder | https://search.murata.co.jp/Ceramy/image/img/A01X/G101/ENG/GCM21BR72A104KA37-01.pdf,https://search.murata.co.jp/Ceramy/image/img/A01X/G101/ENG/GRM21BZ71E106KE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
C1,C2 | 2 | 220uF |  |  |  | 20SVPG220M:CAP_20SVPG220M | https://mm.digikey.com/Volume0/opasdata/d220001/medias/docus/7188/20SVPG.pdf

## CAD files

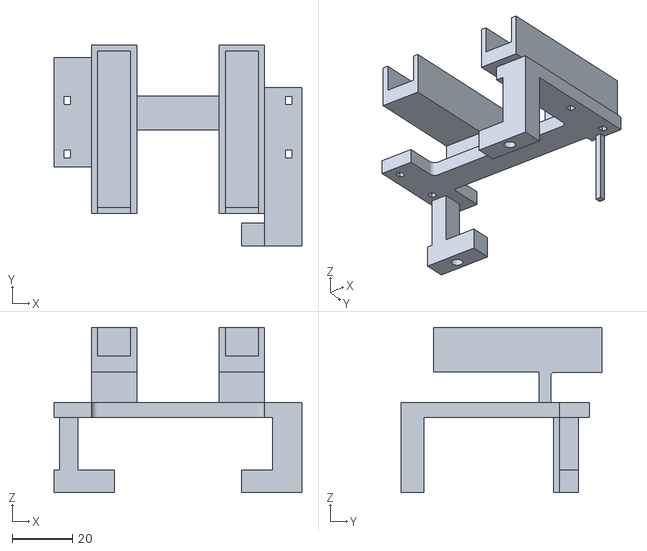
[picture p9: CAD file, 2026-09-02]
hardware/fusion/chassis.stl
82.4 x 66.9 x 54.9

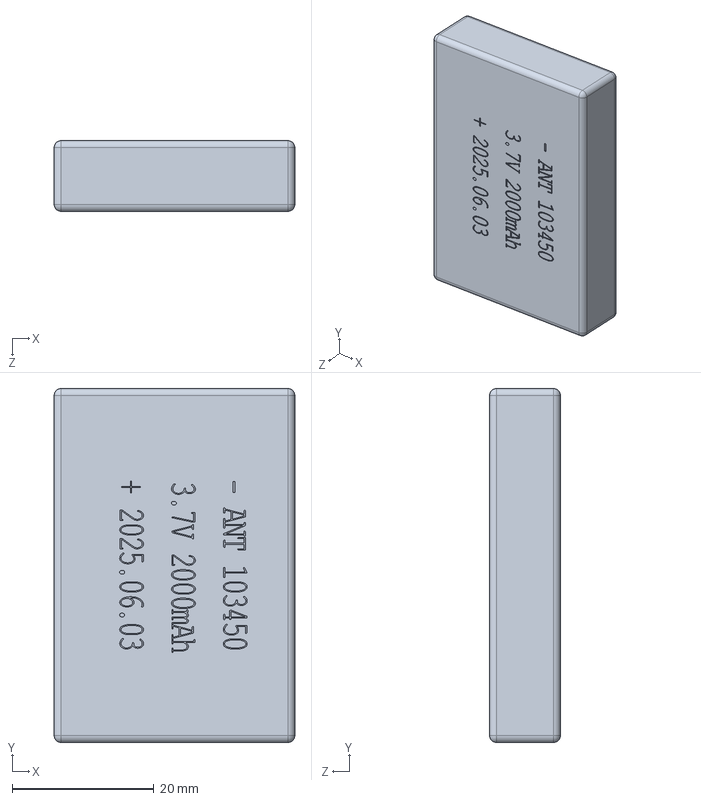
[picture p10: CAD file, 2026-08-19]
hardware/fusion/lithium-polymer-battery-103450-2000mah-1.snapshot.2/LiPo_103450_2000mAh.STEP
34.0 x 50.0 x 10.0 mm

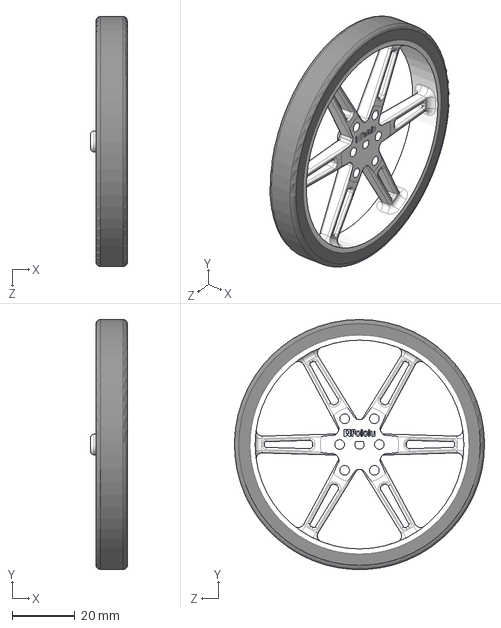
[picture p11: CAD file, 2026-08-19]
hardware/fusion/pololu-wheel-80×10mm/pololu-wheel-80x10mm-white.step
11.8 x 80.0 x 80.0 mm

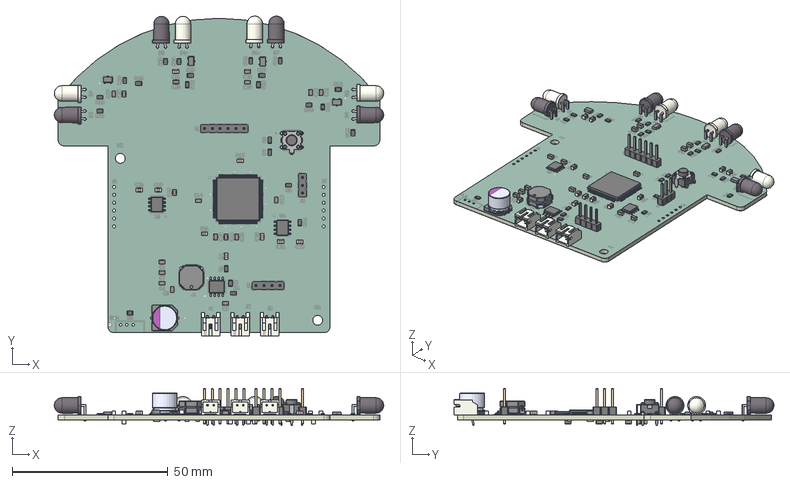
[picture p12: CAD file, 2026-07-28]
hardware/pcb/board.step
105.9 x 102.8 x 12.0 mm
C_0805_2012Metric x 31
R_0805_2012Metric x 29
HTSOP-8-1EP_3.9x4.9mm_P1.27mm x 2
LED_D5.0mm_Horizontal_O1.27mm_Z3.0mm_IRBlack x 4
SSM3K324R,LF x 4
LED_D5.0mm_Horizontal_O1.27mm_Z3.0mm_Clear x 4
PinHeader_1x04_P2.54mm_Vertical
SW_TH_Tactile_Omron_B3F-112x
1217AS-H-4R7N_P3
JST_PH_S2B-PH-K_1x02_P2.00mm_Horizontal x 3
20SVPG220M
LQFP-100_14x14mm_P0.5mm
PinHeader_1x03_P2.54mm_Vertical
PinHeader_1x06_P2.54mm_Vertical
HSOP-8-1EP_3.9x4.9mm_P1.27mm_EP2.41x3.1mm
L_0805_2012Metric
TMPM4KNF10AFG_silkscreen x 2
TMPM4KNF10AFG_soldermask x 2
TMPM4KNF10AFG_PCB

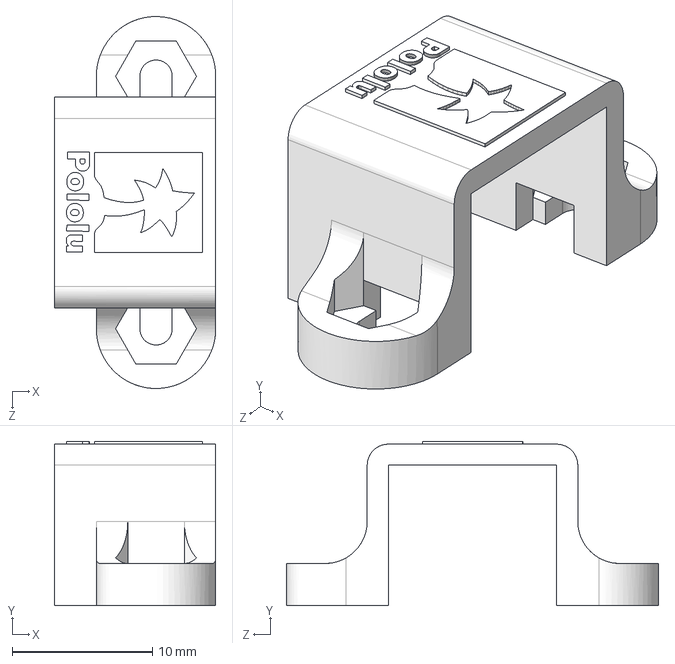
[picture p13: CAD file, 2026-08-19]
hardware/fusion/micro-metal-gearmotor-bracket.step
11.5 x 11.7 x 26.5 mm

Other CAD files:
hardware/fusion/pololu-wheel-80×10mm/pololu-wheel-80x10mm-red.step
hardware/fusion/pololu-wheel-80×10mm/pololu-wheel-80x10mm-yellow.step
hardware/fusion/pololu-wheel-80×10mm/pololu-wheel-80x10mm-blue.step
hardware/fusion/pololu-wheel-80×10mm/pololu-wheel-80x10mm-black.step
hardware/fusion/lithium-polymer-battery-103450-2000mah-1.snapshot.2/LiPo_103450_2000mAh.SLDPRT

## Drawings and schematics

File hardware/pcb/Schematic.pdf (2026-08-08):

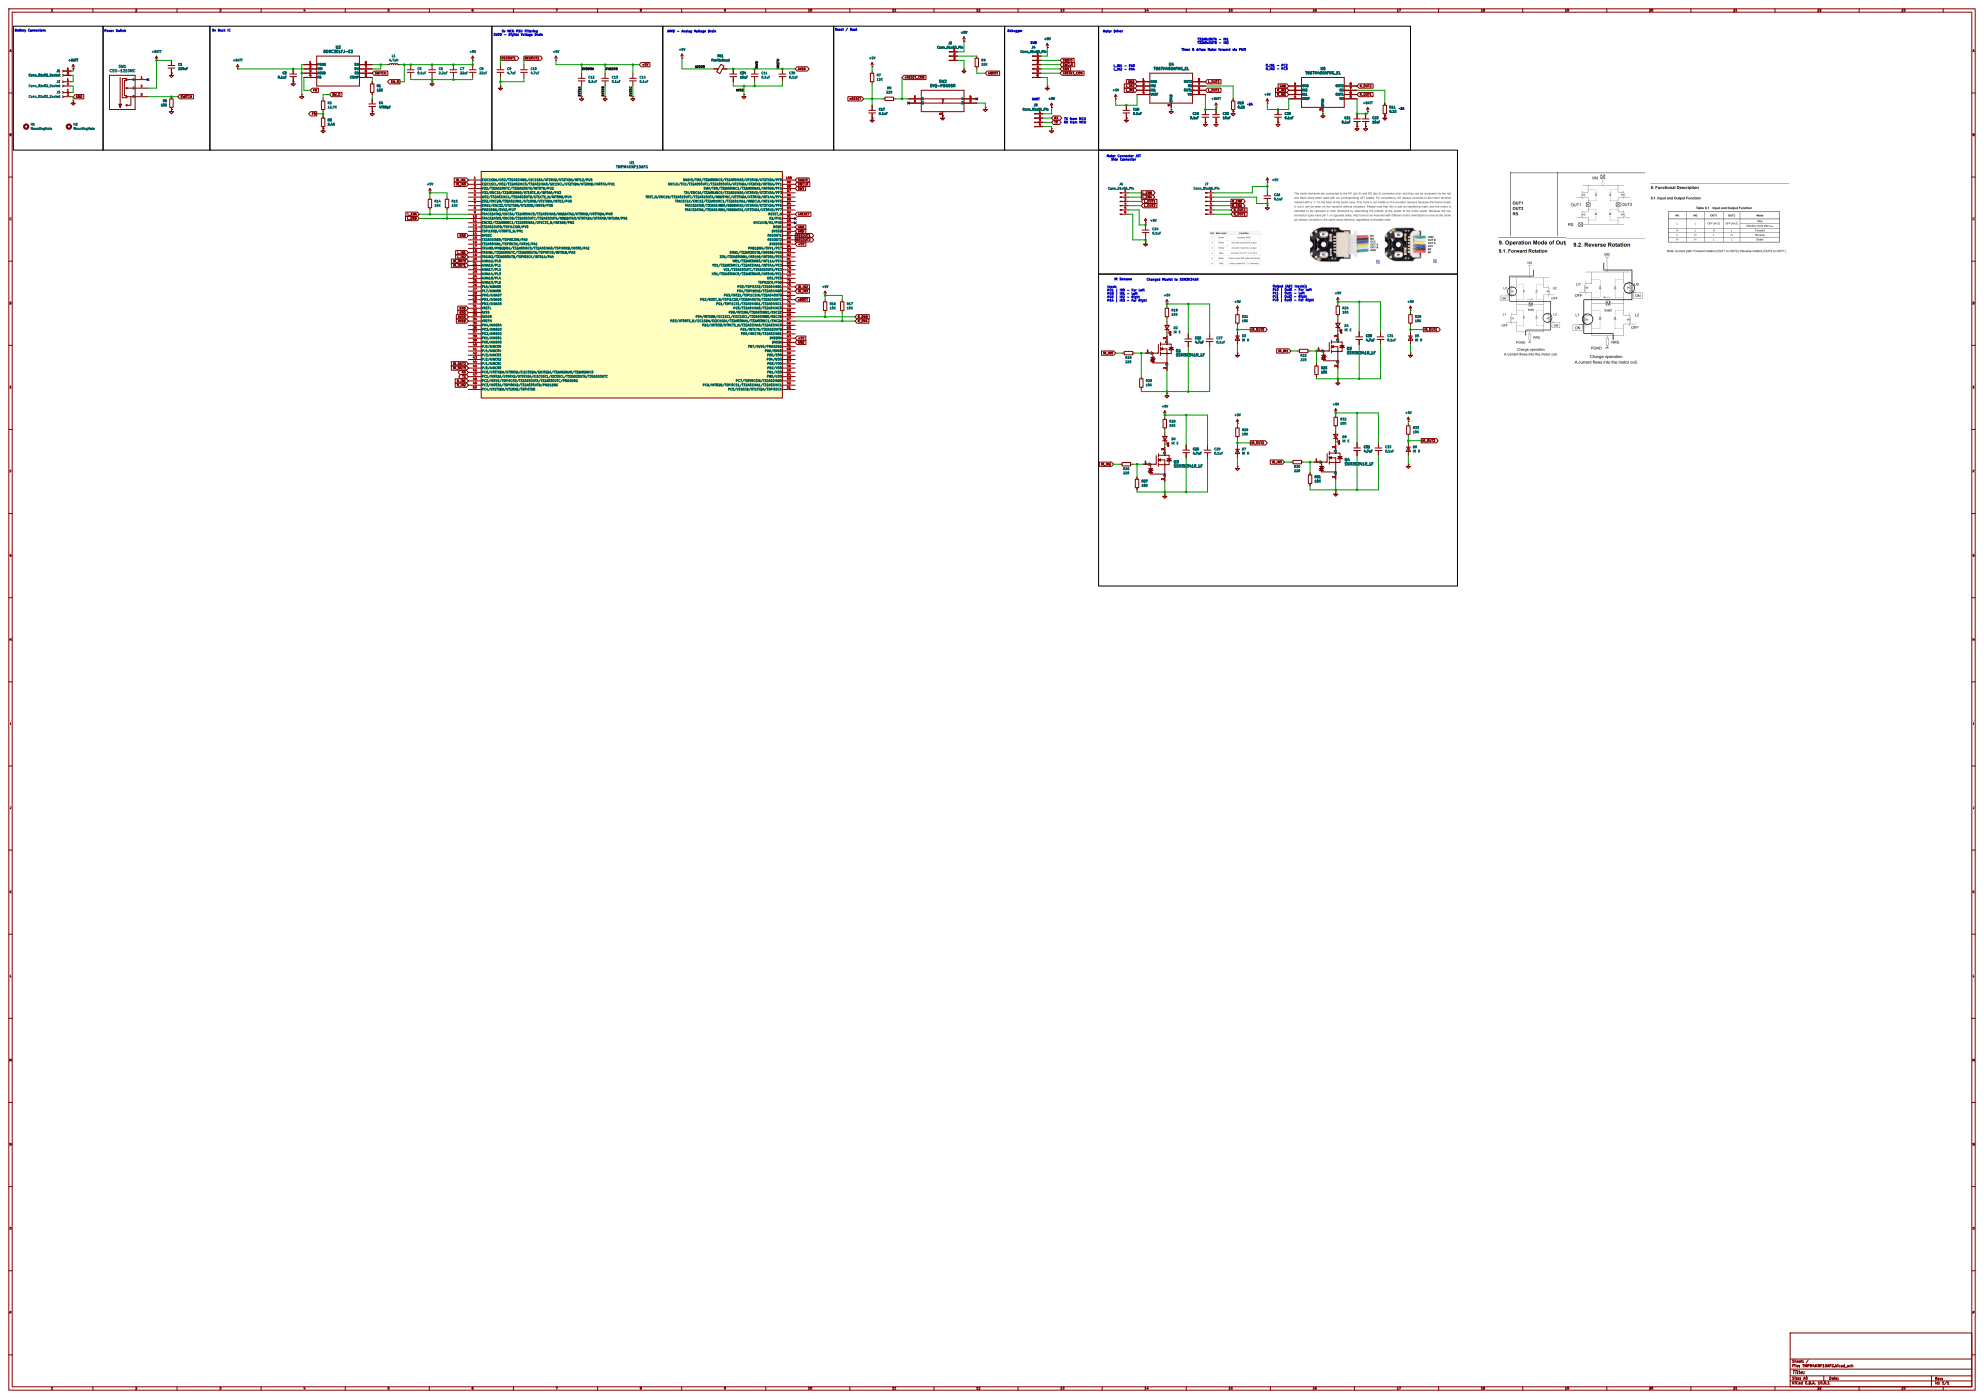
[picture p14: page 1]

Timer B drives Motor forward via PWM

Input: PU1 | IR0 - Far Left PU0 | IR1 - Left PG5 | IR2 - Right PG4 | IR3 - Far Right

Output (ADC Inputs): PL0 | Out0 - Far Left PL1 | Out1 - Left PJ1 | Out2 - Right PJ0 | Out3 - Far Right

Size: A0 | Rev:
KiCad E.D.A. 10.0.1 | Id: 1/1

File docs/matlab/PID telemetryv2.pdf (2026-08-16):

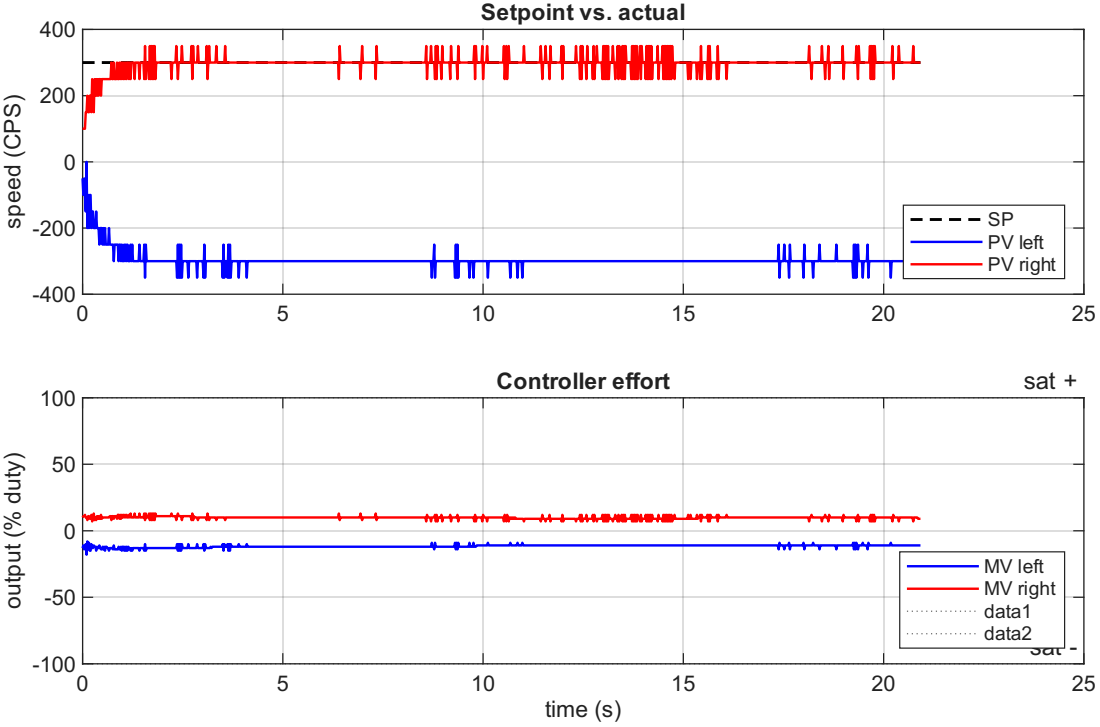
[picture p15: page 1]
speed (CPS); oin; tim; output (% duty); olle; ffo

P V le ft P V rig h t

M V le ft M V rig h t
d a t a 1 d a t a 2 s a t -

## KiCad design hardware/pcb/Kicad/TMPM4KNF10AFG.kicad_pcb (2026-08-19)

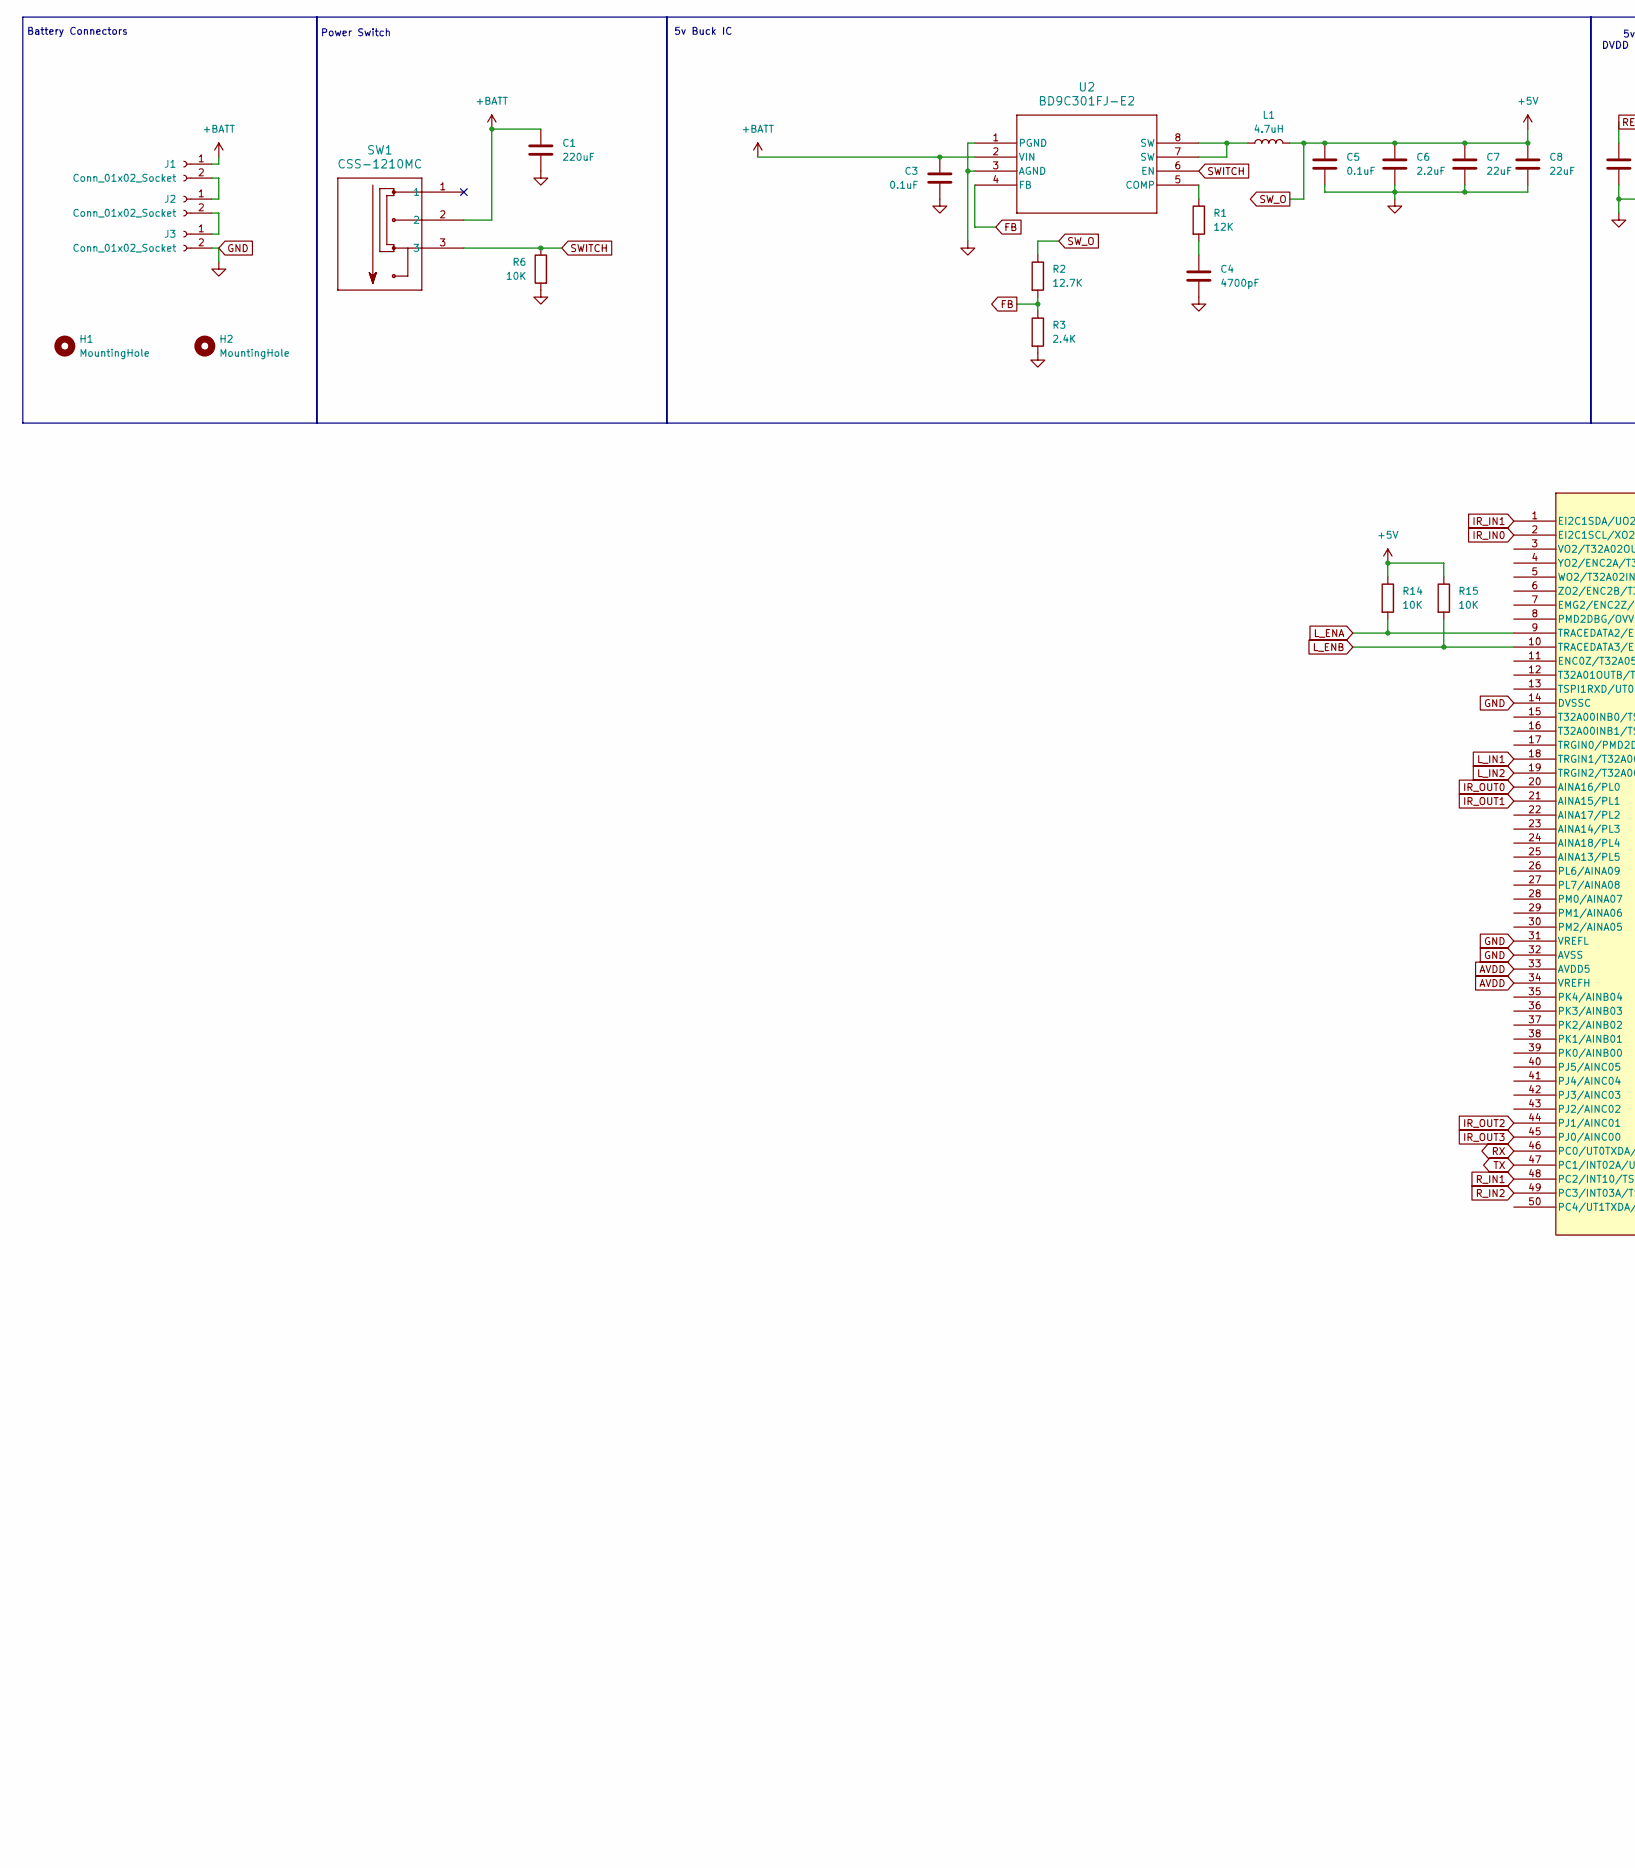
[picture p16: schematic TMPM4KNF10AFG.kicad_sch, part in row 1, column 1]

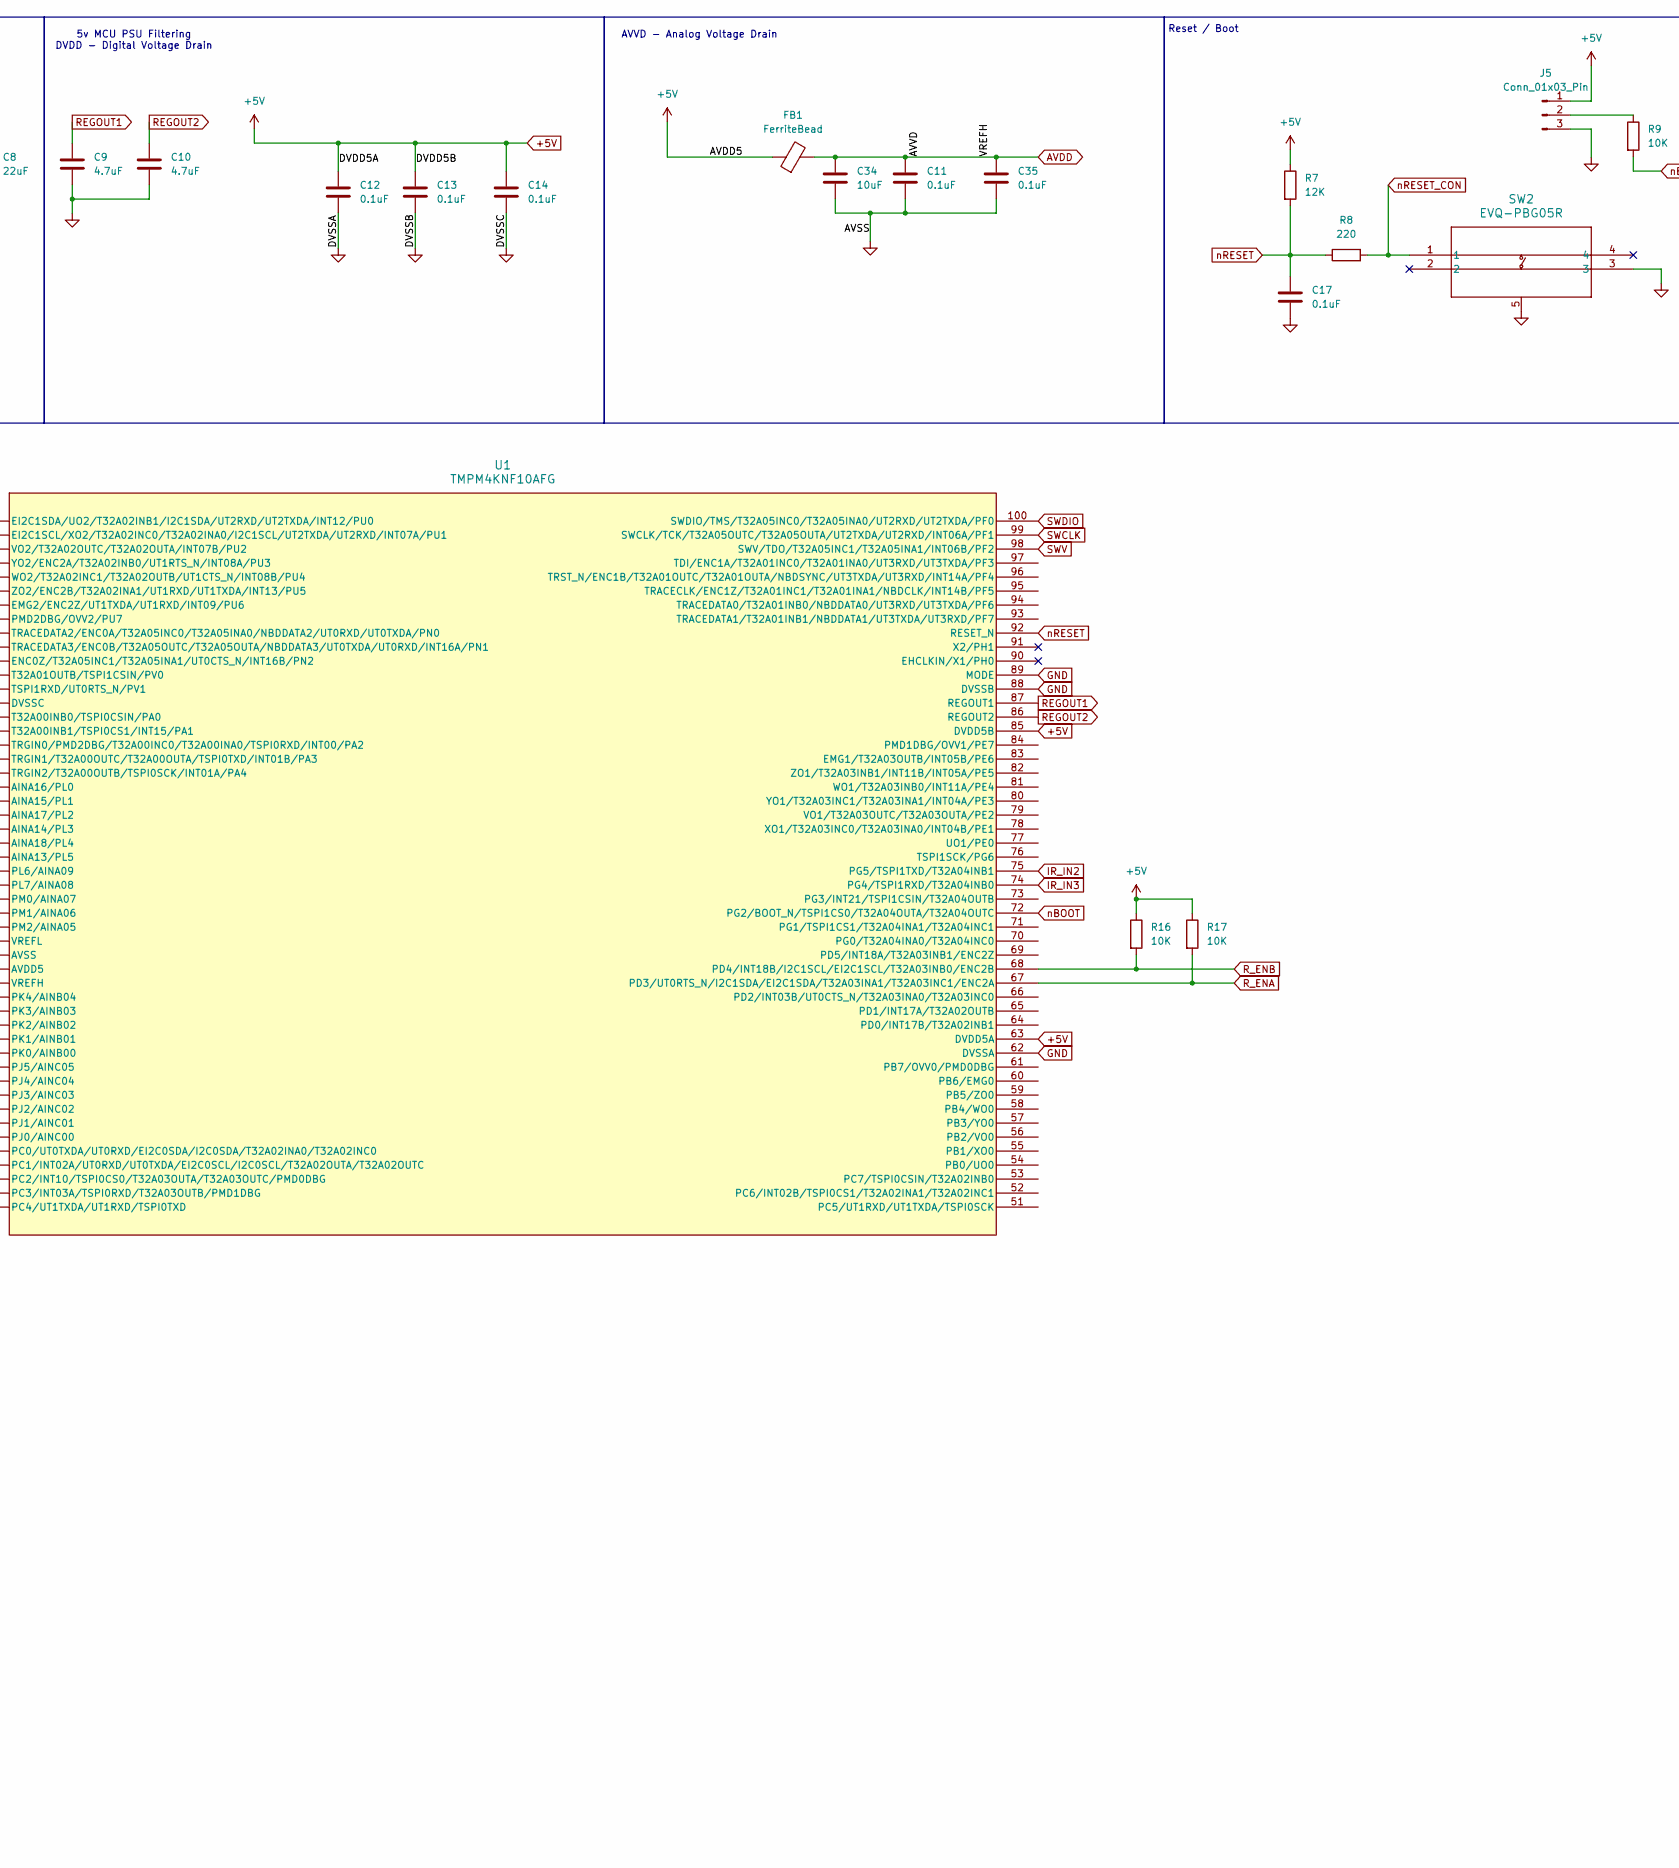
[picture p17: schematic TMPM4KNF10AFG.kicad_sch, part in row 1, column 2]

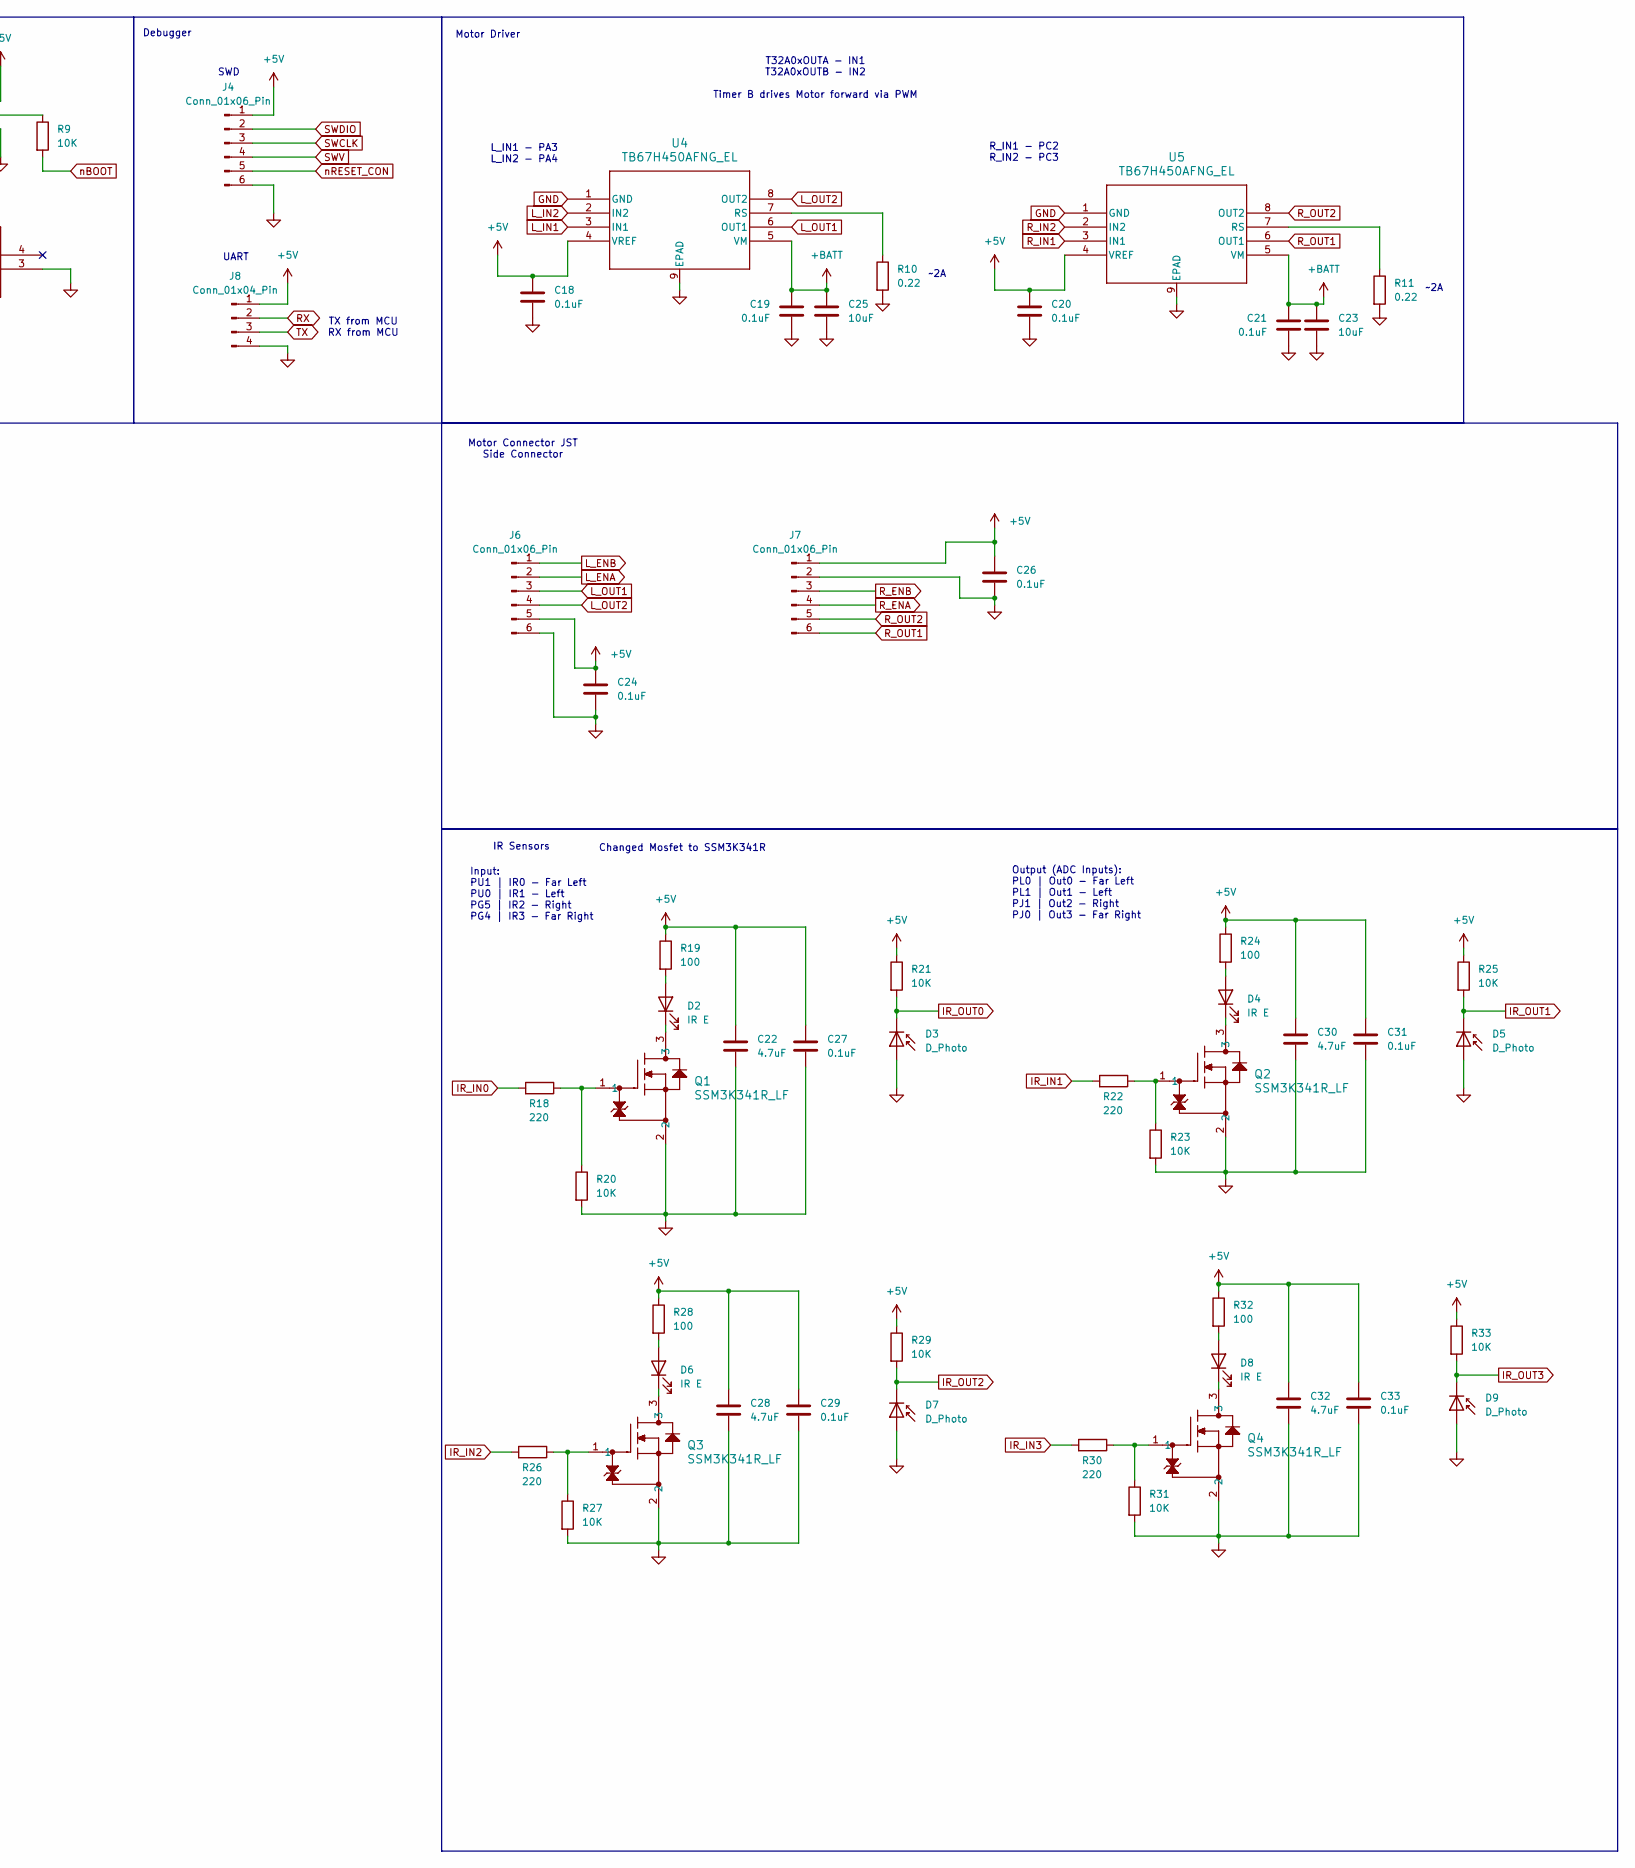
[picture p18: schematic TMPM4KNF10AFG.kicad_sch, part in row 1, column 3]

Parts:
C1: 220uF; CAP_20SVPG220M
C3, C5, C11, C12, C13, C14, C17, C18, C19, C20, C21, C24, C26, C27, C29, C31, C33, C35: 0.1uF; C_0805_2012Metric_Pad1.18x1.45mm_HandSolder
C4: 4700pF; C_0805_2012Metric_Pad1.18x1.45mm_HandSolder
C6: 2.2uF; C_0805_2012Metric_Pad1.18x1.45mm_HandSolder
C7, C8: 22uF; C_0805_2012Metric_Pad1.18x1.45mm_HandSolder
C9, C10, C22, C28, C30, C32: 4.7uF; C_0805_2012Metric_Pad1.18x1.45mm_HandSolder
C23, C25, C34: 10uF; C_0805_2012Metric_Pad1.18x1.45mm_HandSolder
D2, D4, D6, D8: IR E; LED_D5.0mm_Horizontal_O1.27mm_Z3.0mm_Clear
D3, D5, D7, D9: D_Photo; LED_D5.0mm_Horizontal_O1.27mm_Z3.0mm_IRBlack
FB1: FerriteBead; L_0805_2012Metric_Pad1.05x1.20mm_HandSolder
H1, H2: MountingHole; MountingHole_3.2mm_M3
J1, J2, J3: Conn_01x02_Socket; JST_PH_S2B-PH-K_1x02_P2.00mm_Horizontal
J4: Conn_01x06_Pin; PinHeader_1x06_P2.54mm_Vertical
J5: Conn_01x03_Pin; PinHeader_1x03_P2.54mm_Vertical
J6, J7: Conn_01x06_Pin; PAD_01x06_2.54mm
J8: Conn_01x04_Pin; PinHeader_1x04_P2.54mm_Vertical
L1: 4.7uH; IND_1217AS-H-4R7N=P3
Q1, Q2, Q3, Q4: SSM3K341R_LF; SOT-23F_TOS
R1, R7: 12K; R_0805_2012Metric_Pad1.20x1.40mm_HandSolder
R2: 12.7K; R_0805_2012Metric_Pad1.20x1.40mm_HandSolder
R3: 2.4K; R_0805_2012Metric_Pad1.20x1.40mm_HandSolder
R6, R9, R14, R15, R16, R17, R20, R21, R23, R25, R27, R29, R31, R33: 10K; R_0805_2012Metric_Pad1.20x1.40mm_HandSolder
R8, R18, R22, R26, R30: 220; R_0805_2012Metric_Pad1.20x1.40mm_HandSolder
R10, R11: 0.22; R_0805_2012Metric_Pad1.20x1.40mm_HandSolder
R19, R24, R28, R32: 100; R_0805_2012Metric_Pad1.20x1.40mm_HandSolder
SW1: CSS-1210MC; SW3_CSS-1210MC_NDC
SW2: EVQ-PBG05R; EVQ-PBG05R_PAN
U1: TMPM4KNF10AFG; P-LQFP100-1414-0p50-002_TOS
U2: BD9C301FJ-E2; SOP-J8_ROM
U4, U5: TB67H450AFNG_EL; P-HSOP8-0405-1.27-002_TOS

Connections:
+5V: C5.1, C6.1, C7.1, C8.1, C12.1, C13.1, C14.1, C18.1, C20.1, C22.1, C24.1, C26.1, C27.1, C28.1, C29.1, C30.1, C31.1, C32.1, C33.1, FB1.1, J4.1, J5.1, J6.5, J7.1, J8.1, L1.2, R2.1, R7.1, R14.1, R15.1, R16.1, R17.1, R19.1, R21.1, R24.1, R25.1, R28.1, R29.1, R32.1, R33.1, U1.63 (DVDD5A), U1.85 (DVDD5B), U4.4 (VREF), U5.4 (VREF)
+BATT: C1.1, C3.1, C19.1, C21.1, C23.1, C25.1, J1.1, SW1.2, U2.2 (VIN), U4.5 (VM), U5.5 (VM)
AVDD: C11.1, C34.1, C35.1, FB1.2, U1.33 (AVDD5), U1.34 (VREFH)
FB: R2.2, R3.1, U2.4 (FB)
GND: C1.2, C3.2, C4.2, C5.2, C6.2, C7.2, C8.2, C9.2, C10.2, C11.2, C12.2, C13.2, C14.2, C17.2, C18.2, C19.2, C20.2, C21.2, C22.2, C23.2, C24.2, C25.2, C26.2, C27.2, C28.2, C29.2, C30.2, C31.2, C32.2, C33.2, C34.2, C35.2, D3.2 (A), D5.2 (A), D7.2 (A), D9.2 (A), J3.2, J4.6, J5.3, J6.6, J7.2, J8.4, Q1.2, Q2.2, Q3.2, Q4.2, R3.2, R6.2, R10.2, R11.2, R20.2, R23.2, R27.2, R31.2, SW2.3, SW2.5, U1.14 (DVSSC), U1.31 (VREFL), U1.32 (AVSS), U1.62 (DVSSA), U1.88 (DVSSB), U1.89 (MODE), U2.1 (PGND), U2.3 (AGND), U4.1 (GND), U4.9 (EPAD), U5.1 (GND), U5.9 (EPAD)
IR_IN0: R18.2, U1.2 (EI2C1SCL/XO2/T32A02INC0/T32A02INA0/I2C1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)
IR_IN1: R22.2, U1.1 (EI2C1SDA/UO2/T32A02INB1/I2C1SDA/UT2RXD/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)
IR_IN2: R26.2, U1.75 (PG5/TSPI1TXD/T32A04INB1)
IR_IN3: R30.2, U1.74 (PG4/TSPI1RXD/T32A04INB0)
IR_OUT0: D3.1 (K), R21.2, U1.20 (AINA16/PL0)
IR_OUT1: D5.1 (K), R25.2, U1.21 (AINA15/PL1)
IR_OUT2: D7.1 (K), R29.2, U1.44 (PJ1/AINC01)
IR_OUT3: D9.1 (K), R33.2, U1.45 (PJ0/AINC00)
L_ENA: J6.2, R14.2, U1.9 (TRACEDATA2/ENC0A/T32A05INC0/T32A05INA0/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)
L_ENB: J6.1, R15.2, U1.10 (TRACEDATA3/ENC0B/T32A05OUTC/T32A05OUTA/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)
L_IN1: U1.18 (TRGIN1/T32A00OUTC/T32A00OUTA/TSPI0TXD/I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), U4.3 (IN1)
L_IN2: U1.19 (TRGIN2/T32A00OUTB/TSPI0SCK/INT01A/PA4), U4.2 (IN2)
L_OUT1: J6.3, U4.6 (OUT1)
L_OUT2: J6.4, U4.8 (OUT2)
unnamed: C4.1, R1.2
unnamed: D2.2 (A), R19.2
unnamed: D2.1 (K), Q1.3
unnamed: D4.2 (A), R24.2
unnamed: D4.1 (K), Q2.3
unnamed: D6.2 (A), R28.2
unnamed: D6.1 (K), Q3.3
unnamed: D8.2 (A), R32.2
unnamed: D8.1 (K), Q4.3
unnamed: J1.2, J2.1
unnamed: J2.2, J3.1
unnamed: J5.2, R9.1
unnamed: L1.1, U2.7 (SW), U2.8 (SW)
unnamed: Q1.1, R18.1, R20.1
unnamed: Q2.1, R22.1, R23.1
unnamed: Q3.1, R26.1, R27.1
unnamed: Q4.1, R30.1, R31.1
unnamed: R1.1, U2.5 (COMP)
unnamed: R10.1, U4.7 (RS)
unnamed: R11.1, U5.7 (RS)
REGOUT1: C9.1, U1.87 (REGOUT1)
REGOUT2: C10.1, U1.86 (REGOUT2)
RX: J8.2, U1.46 (PC0/UT0TXDA/UT0RXD/EI2C0SDA/I2C0SDA/T32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)
R_ENA: J7.4, R17.2, U1.67 (PD3/UT0RTS_N/I2C1SDA/EI2C1SDA/T32A03INA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)
R_ENB: J7.3, R16.2, U1.68 (PD4/INT18B/I2C1SCL/EI2C1SCL/T32A03INB0/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)
R_IN1: U1.48 (PC2/INT10/TSPI0CS0/T32A03OUTA/T32A03OUT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), U5.3 (IN1)
R_IN2: U1.49 (PC3/INT03A/TSPI0RXD/T32A03OUTB/PMD1DBG), U5.2 (IN2)
R_OUT1: J7.6, U5.6 (OUT1)
R_OUT2: J7.5, U5.8 (OUT2)
SWCLK: J4.3, U1.99 (SWCLK/TCK/T32A05OUTC/T32A05OUTA/UT2TXDA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)
SWDIO: J4.2, U1.100 (SWDIO/TMS/T32A05INC0/T32A05INA0/UT2RXD/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)
SWITCH: R6.1, SW1.3, U2.6 (EN)
SWV: J4.4, U1.98 (SWV/TDO/T32A05INC1/T32A05INA1/INT06B/PF2)
TX: J8.3, U1.47 (PC1/INT02A/UT0RXD/UT0TXDA/EI2C0SCL/I2C0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)
nBOOT: R9.2, U1.72 (PG2/BOOT_N/TSPI1CS0/T32A04OUTA/T32A04OU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)
nRESET: C17.1, R7.2, R8.1, U1.92 (RESET_N)
nRESET_CON: J4.5, R8.2, SW2.1

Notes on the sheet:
Battery Connectors
TX from MCU RX from MCU
R_IN1 - PC2 R_IN2 - PC3
Motor Connector JST Side Connector
Changed Mosfet to SSM3K341R
UART
Output (ADC Inputs): PL0 | Out0 - Far Left PL1 | Out1 - Left PJ1 | Out2 - Right PJ0 | Out3 - Far Right
5v MCU PSU Filtering DVDD - Digital Voltage Drain
IR Sensors
T32A0xOUTA - IN1 T32A0xOUTB - IN2 Timer B drives Motor forward via PWM
Power Switch
Debugger
5v Buck IC
~2A
L_IN1 - PA3 L_IN2 - PA4
Motor Driver
SWD
AVVD - Analog Voltage Drain
Input: PU1 | IR0 - Far Left PU0 | IR1 - Left PG5 | IR2 - Right PG4 | IR3 - Far Right
Reset / Boot

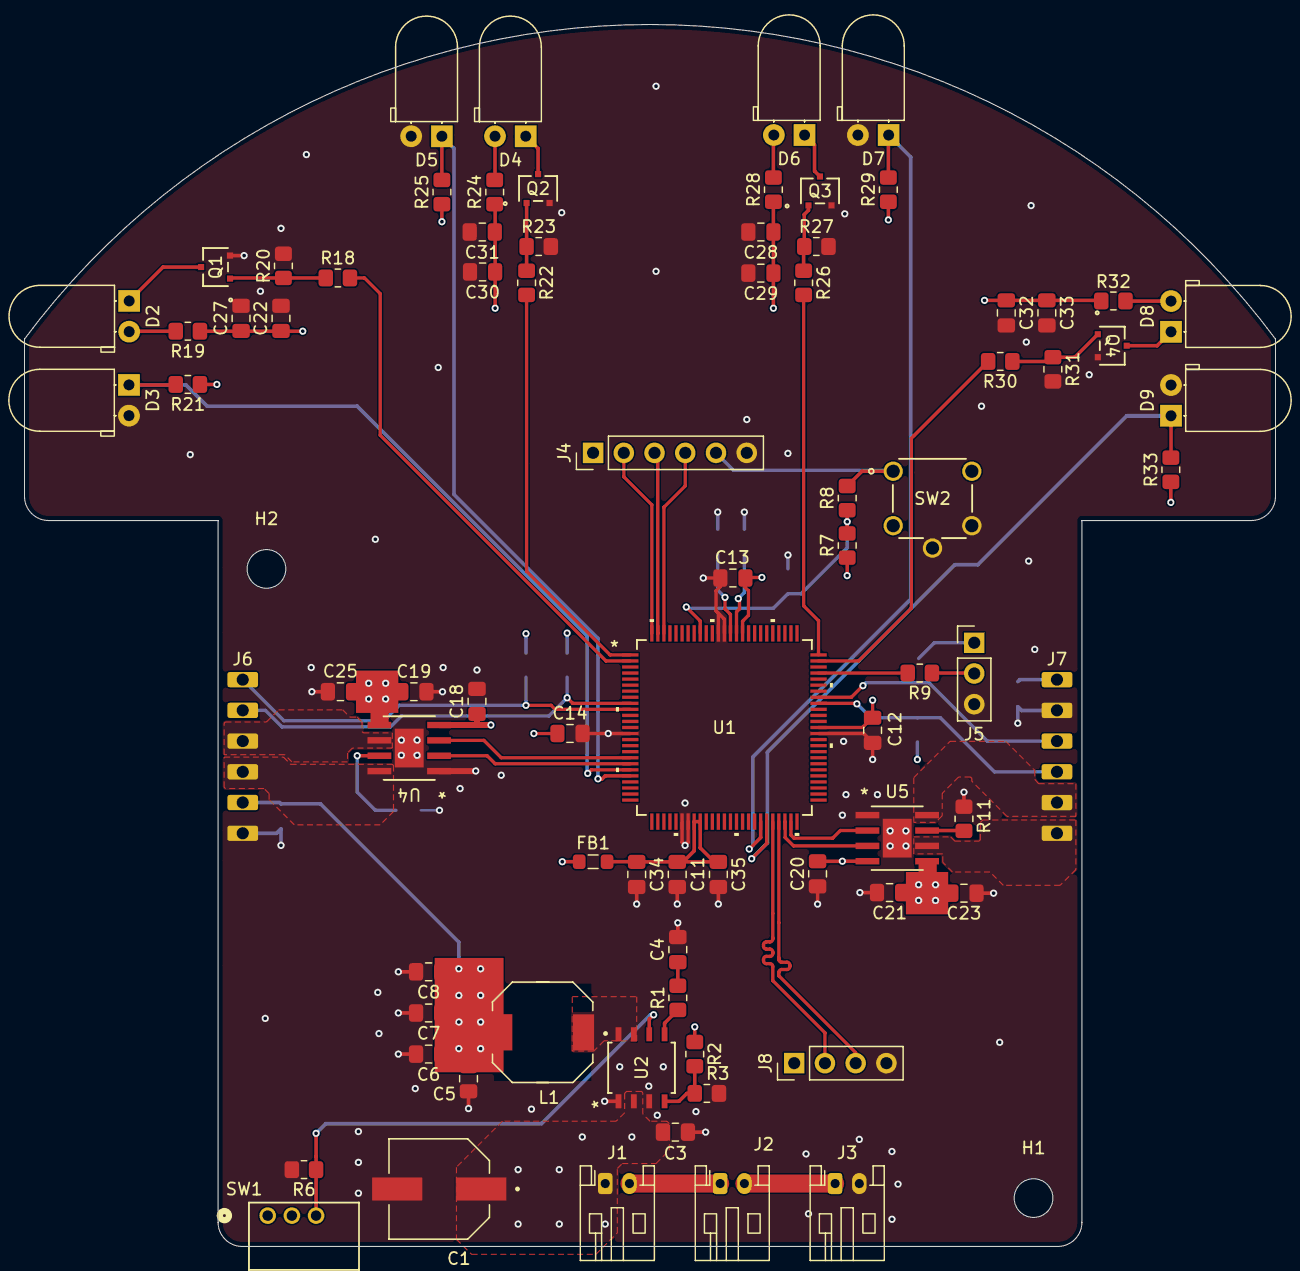
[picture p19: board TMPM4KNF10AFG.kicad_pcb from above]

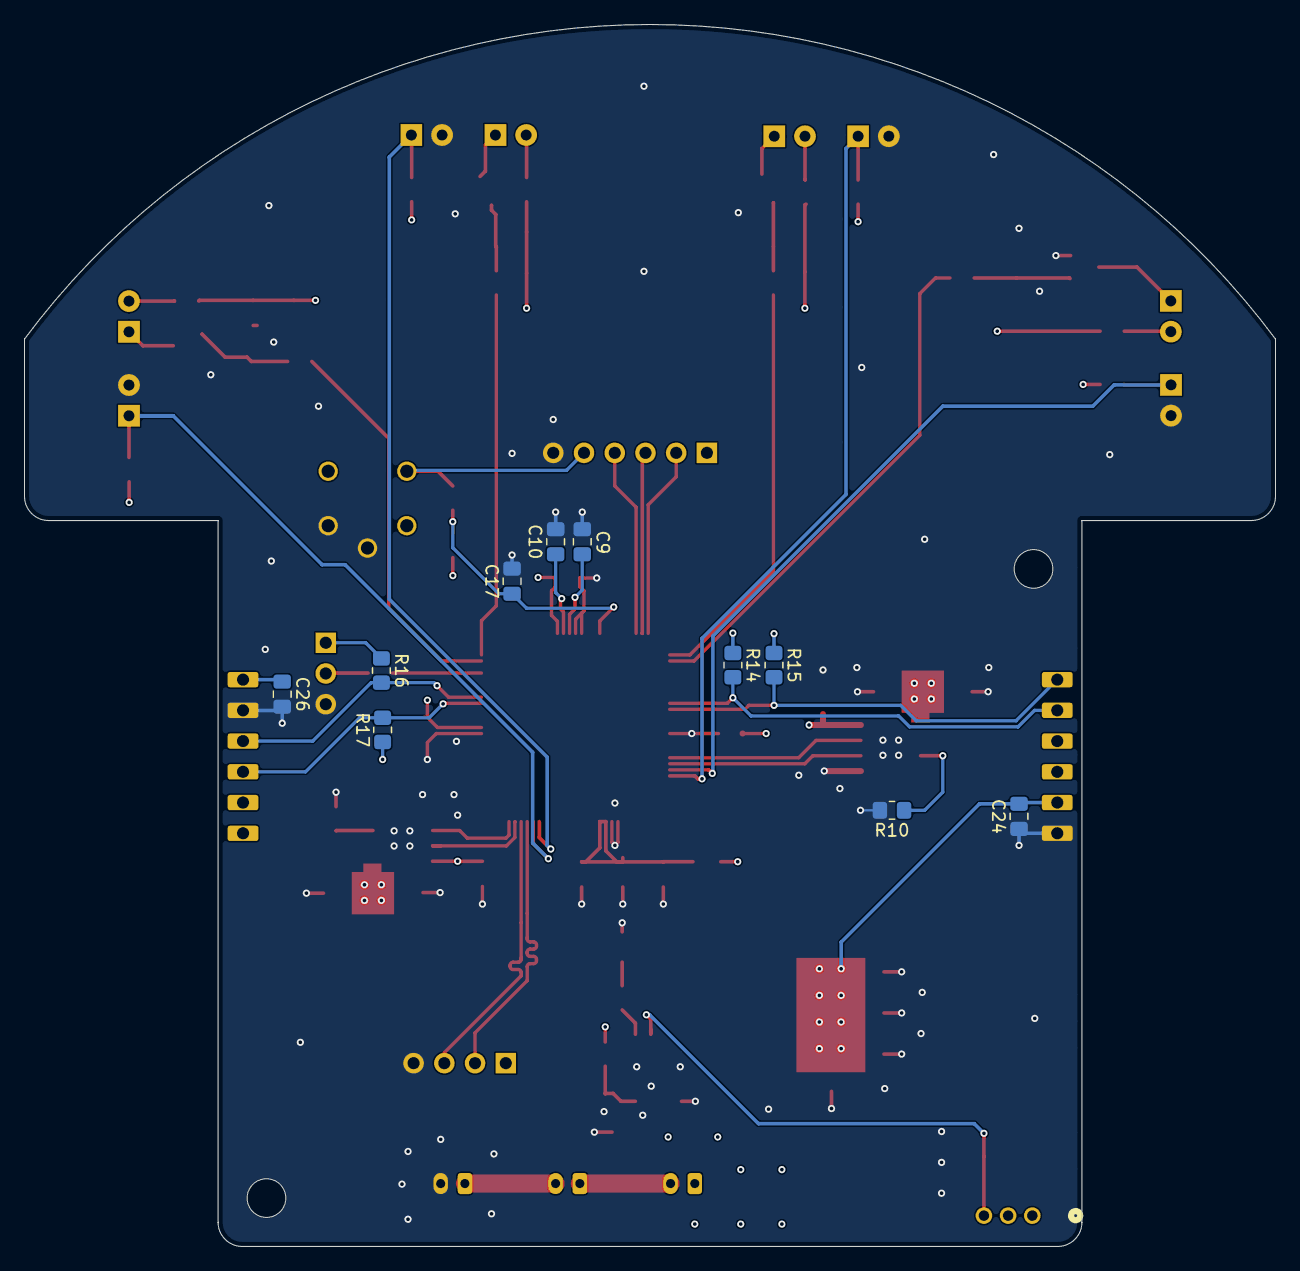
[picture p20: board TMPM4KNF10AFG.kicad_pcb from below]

Board: 4 copper layers, 103.4 x 101.0 mm, 91 parts (10 on the bottom side), 56 nets.

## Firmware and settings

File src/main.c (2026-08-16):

/**
 ******************************************************************************
 * @file        main.c
 * @brief       Micromouse main firmware entry point
 * @version     V1.0.0
 * @date        05-05-2026
 *
 * @details
 *   Initializes the system clock and all modules, then runs the main control
 *   loop. Every 1 kHz tick (T32A1 interval timer) runs the full pipeline in
 *   fixed order:
 *
 *     Encoder_Update()   -> read quadrature counters, filter wheel speed
 *     Odometry_Update()  -> integrate pose (x, y, heading) from encoders
 *     Motion_Update()    -> PID speed loop, drive motor PWM (ALWAYS runs)
 *     Navigator_Update() -> non-blocking FSM: plan -> turn -> drive -> pause
 *
 *   Navigator is the top-level brain: it calls FloodFill (pure planner) for
 *   the next move, then sequences the physical turn/drive without ever
 *   blocking, so the PID loop above keeps running every tick.
 *
 *   Deployment calibration (must set before real runs):
 *   - IrSensor.c : ir_cal[] table (measured ADC-to-distance points)
 *   - Odometry.h : WHEELBASE_MM (measure wheel-center to wheel-center)
 *   - Encoder    : confirm forward motion yields INCREASING position
 *   - PID.h      : tune gains for CPS-scaled error
 *
 * ___________________________________________________________________________
 * Hardware:
 *   - MCU:     TMPM4KNF10AFG (ARM Cortex-M4, 5V, 160 MHz)
 *   - Motors:  TB67H450AFNG x2 + Pololu #5211 N20 30:1
 *   - Sensors: IR emitter/receiver pairs x4
 *   - Debug:   External CMSIS-DAP w/ Level Shifter (TXB0104)
 *
 * ___________________________________________________________________________
 * Pin Assignment:
 *   ┌─────────────────────────────────────────────────────────────┐
 *   │  PORT A  │ PA3  = 	 T32A00OUTA  (Left PWM IN1)            │
 *   │          │ PA4  = 	 T32A00OUTB  (Left PWM IN2)            │
 *   ├─────────────────────────────────────────────────────────────┤
 *   │  PORT C  │ PC2  = 	 T32A30OUTA  (Right PWM IN1)           │
 *   │          │ PC3  = 	 T32A30OUTB  (Right PWM IN2)           │
 *   ├─────────────────────────────────────────────────────────────┤
 *   │  PORT N  │ PN0  = 	 ENC0A  (Left encoder A)               │
 *   │          │ PN1  = 	 ENC0B  (Left encoder B)               │
 *   ├─────────────────────────────────────────────────────────────┤
 *   │  PORT D  │ PD3  = 	 ENC2A  (Right encoder A)              │
 *   │          │ PD4  = 	 ENC2B  (Right encoder B)              │
 *   ├─────────────────────────────────────────────────────────────┤
 *   │  PORT L  │ PL0  = 	 AINA16  (Far Left IR)                 │
 *   │          │ PL1  = 	 AINA15  (Left IR)                     │
 *   ├─────────────────────────────────────────────────────────────┤
 *   │  PORT J  │ PJ0  =     AINC00  (Far Right IR)                │
 *   │          │ PJ1  = 	 AINC01  (Right IR)                    │
 *   ├─────────────────────────────────────────────────────────────┤
 *   │  PORT U  │ PU0  =     Left IR Emitter                       │
 *   │          │ PU1  =     Far Left IR Emitter                   │
 *   ├─────────────────────────────────────────────────────────────┤
 *   │  PORT G  │ PG4  =     Far Right IR Emitter                  │
 *   │          │ PG5  =     Right IR Emitter                      │
 *   └─────────────────────────────────────────────────────────────┘
 *
 * ___________________________________________________________________________
 * Aliases (for quick reference):
 *   - PA3 = IN1, PA4 = IN2  (Left motor, T32A00OUTA/B)
 *   - PC2 = IN1, PC3 = IN2  (Right motor, T32A30OUTA/B)
 *   - PN0 = ENC0A, PN1 = ENC0B  (Left encoder)
 *   - PD3 = ENC2A, PD4 = ENC2B  (Right encoder)
 *   - PL0 = AINA16 (Far Left IR), PL1 = AINA15 (Left IR)
 *   - PJ1 = AINC01 (Right IR), PJ0 = AINC00 (Far Right IR)
 *   - PU1 = Far Left IR Emitter, PU0 = Left IR Emitter
 *   - PG5 = Right IR Emitter, PG4 = Far Right IR Emitter
 *
 * ___________________________________________________________________________
 * Notes:
 *   - MCU must be powered at 5V for ADC to function.
 *   - See TMPM4KNF10AFG datasheet section 7.2.
 *
 * ___________________________________________________________________________
 * References:
 *   - Product Info:  https://toshiba.semicon-storage.com/info/TXZP-PINFO-M4K(2)_en_20231225.pdf?did=70854
 *   - Datasheet:     https://toshiba.semicon-storage.com/info/TMPM4KNF10AFG_datasheet_en_20250516.pdf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
 *
 * Copyright (c) [Kevin Le] 2026
 ******************************************************************************
 */


/* Inclusions */
#include "TMPM4KyA.h"
#include "system_TMPM4KyA.h"
#include "modules/Timebase.h"    // 1 kHz tick flag (T32A1)
#include "modules/Encoder.h"     // quadrature speed + position
#include "modules/Odometry.h"    // pose estimate (x, y, heading)
#include "modules/Motion.h"      // PID speed loop + motor drive
#include "modules/IrSensor.h"    // IR wall sensing (ADC)
#include "modules/FloodFill.h"   // pure maze planner (BFS)
#include "modules/Navigator.h"   // top-level motion sequencer FSM
#include "drivers/uart.h"		 // uart for debugging


void ModuleInit(void);




int main(void)
{
	SystemInit();								/* Initialize system clock and peripherals */
	ModuleInit();
	

	/* Control loop: fires once per 1 kHz tick. Order matters — each stage
	 * consumes the output of the one above it within the same tick.       */
	while (1)
	{
		if (Timebase_GetAndClear())     // true once per 1 ms tick
		{
			Encoder_Update();       // 1. read encoders, filter speed
			Odometry_Update();      // 2. update pose from encoders
			IR_SampleStep();        // 3. sample IR readings
			Navigator_Update();     // 4. plan/turn/drive FSM step
			Motion_Update();        // 5. PID -> motor PWM
		}
	}

	return 0;
}



/**
 * @brief  Initialize all modules in dependency order.
 * @note   Call once after SystemInit().
 *
 *   Each driver configures its own GPIO port internally, so no separate
 *   GPIO_Init() pass is needed. SysTick needs no init (stateless).
 *
 *   Order:
 *   1. Motion   -> Encoder + Motor (PWM T32A0/3, encoder ports) up first
 *   2. Odometry -> caches encoder position, so must follow Motion
 *   3. IR       -> ADC + emitter ports; ADC uses SysTick_us (stateless)
 *   4. FloodFill-> planner; samples IR on first Plan(), so IR must precede it
 *   5. Navigator-> depends on FloodFill + Motion
 *   6. Timebase -> starts 1 kHz tick LAST
 */
void ModuleInit(void)
{
    Motion_Init();      // -> Encoder_Init() + Motor_Init()
    Odometry_Init();    // reads Encoder position
    IR_Init();          // ADC_Init() + emitter ports
    FloodFill_Init();
    Navigator_Init();
    Timebase_Init();    // start tick last
}

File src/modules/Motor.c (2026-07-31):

/**
 * @file        Motor.c
 * @brief       Motor control implementation for TB67H450AFNG (slow-decay)
 * @version     V2.0.0
 * @date        26-07-2026
 *
 * @details
 *   High-level motor control. See motor.h for wiring and truth table.
 *
 *   Direction-change policy (RM-T32A-C 4.6.1):
 *   OUTCRA1 / OUTCRB1 are writable only while RUNA = 0. A direction
 *   change therefore stops the channel, rewrites output control, and
 *   restarts. Duty-only updates (RGx0) are double-buffered and may be
 *   written while the channel runs.
 *
 *     +-------------------------+-------------------------------+
 *     |  Scenario               |  Action                       |
 *     +-------------------------+-------------------------------+
 *     |  Same dir, moving       |  Live duty write only         |
 *     |  Same dir, BRAKE/STOP   |  No-op                        |
 *     |  Any direction change   |  Stop -> reconfigure -> Start |
 *     +-------------------------+-------------------------------+
 *
 *   Drive scheme: SLOW DECAY (IN1 = TimerA/OUTA, IN2 = TimerB/OUTB).
 *   The PWM off-phase is BRAKE (both inputs high), not coast. Winding
 *   current recirculates rather than collapsing each cycle, which
 *   raises low-duty torque and linearises speed-vs-duty relative to
 *   fast decay.
 *
 *   Direction labels denote robot motion. The pin mapping is inverted
 *   relative to the TB67H450 forward/reverse convention so that a
 *   FORWARD command produces forward wheel rotation for the installed
 *   motor wiring.
 *
 *     FORWARD : IN1 = PWM, IN2 = HIGH (static)
 *                 PWM low  -> IN1=L, IN2=H -> drive
 *                 PWM high -> IN1=H, IN2=H -> brake (recirculate)
 *     REVERSE : IN1 = HIGH (static), IN2 = PWM
 *                 PWM low  -> IN1=H, IN2=L -> drive
 *                 PWM high -> IN1=H, IN2=H -> brake (recirculate)
 *     BRAKE   : IN1 = HIGH, IN2 = HIGH  (both outputs low, shorted)
 *     STOP    : IN1 = LOW,  IN2 = LOW   (Hi-Z / standby)
 *
 *   Consequence of slow decay: a direction commanded at 0 % duty holds
 *   the motor in BRAKE, not coast. STOP selects the free/standby state.
 *
 *   Duty geometry (RGx0 is non-inverted in this scheme):
 *   The PWM pin uses T32A_OUTPUT_PPG = SET on CMP0 (RGx0), CLEAR on CMP1
 *   (RGx1 = period). Counting up from 0, the pin is LOW over 0..RGx0 and
 *   HIGH over RGx0..period. In slow decay the drive phase is the PWM-LOW
 *   phase, so drive time equals RGx0 counts and RGx0 maps directly to
 *   duty: RGx0 = speed% * period.
 *
 * @note
 *   File structure and Doxygen formatting assisted by AI.
 *
 * Copyright (c) [Kevin Le] 2026
 */

#include "Motor.h"
#include "drivers/timer32A.h"

#define MAX_DUTY    100U
#define PERIOD_L    ((uint16_t)T32A_CH0_PERIOD)
#define PERIOD_R    ((uint16_t)T32A_CH3_PERIOD)

static motor_dir_t motor_left_dir  = STOP;
static motor_dir_t motor_right_dir = STOP;

/* ==========================================================================
 *   Private helper
 * ========================================================================== */

/**
 * @brief  Convert a speed/duty percentage to a timer compare value (RGx0).
 * @param  duty   Duty in percent, 0-100.
 * @param  period  Timer period in counts.
 * @return Compare value in [0, period-1]; RGx0 equals drive-time counts.
 *
 * @note   Non-inverted (slow-decay sense): a larger value yields more
 *         drive time, since the drive phase is the PWM-LOW interval
 *         (0..RGx0). A speed of 0 gives RGx0 = 0, i.e. full brake.
 */
static uint16_t Duty_ToCompare(uint8_t duty, uint16_t period)
{
    if (duty >= MAX_DUTY)
    {
        return (uint16_t)(period - 1U);     /* Near-full drive (1 count brake) */
    }

    return (uint16_t)((uint32_t)duty * (uint32_t)(period - 1U) / (uint32_t)MAX_DUTY);
}

/* ==========================================================================
 *   Initialization
 * ========================================================================== */

void Motor_Init(void)
{
    T32A0_Init(T32A_CH0_PERIOD);   /* Left motor  */
    T32A3_Init(T32A_CH3_PERIOD);   /* Right motor */

    /* Safe initial state: both inputs LOW (standby / Hi-Z) */
    T32A0_SetOutCRA1(T32A_OUTPUT_LOW);
    T32A0_SetOutCRB1(T32A_OUTPUT_LOW);
    T32A3_SetOutCRA1(T32A_OUTPUT_LOW);
    T32A3_SetOutCRB1(T32A_OUTPUT_LOW);

    motor_left_dir  = STOP;
    motor_right_dir = STOP;
}

/* ==========================================================================
 *   Start / Stop
 * ========================================================================== */

void Motor_Start(void)
{
    T32A0_Start();
    T32A3_Start();
}

void Motor_Stop(void)
{
    Motor_SetLeft(STOP, 0U);
    Motor_SetRight(STOP, 0U);

    T32A0_Stop();
    T32A3_Stop();
}

/* ==========================================================================
 *   Left motor  (T32A0: IN1 = A/OUTA, IN2 = B/OUTB)
 * ========================================================================== */

void Motor_SetLeft(motor_dir_t dir, uint8_t speed)
{
    uint16_t duty = Duty_ToCompare(speed, PERIOD_L);
 
    /* Fast path: same direction, update the PWM leg's duty only. FORWARD drives the PWM on IN1 (A); REVERSE on IN2 (B). */
    if (dir == motor_left_dir)
    {
        if (dir == FORWARD)
        {
            T32A0_SetTimerA0(duty);   /* IN1 is the PWM leg in FORWARD */
        }
        else if (dir == REVERSE)
        {
            T32A0_SetTimerB0(duty);   /* IN2 is the PWM leg in REVERSE */
        }
        /* BRAKE / STOP: no live update required */
        return;
    }
 
    /* Full path: stop, reconfigure output control, restart */
    T32A0_Stop();
 
    switch (dir)
    {
        /* Slow-decay forward: IN1 PWM, IN2 static HIGH (PWM low = drive) */
        case FORWARD:
            T32A0_SetOutCRA1(T32A_OUTPUT_PPG);       /* IN1 = PWM         */
            T32A0_SetOutCRB1(T32A_OUTPUT_HIGH);      /* IN2 = static HIGH */
            T32A0_SetTimerA0(duty);
            T32A0_SetTimerB0(0U);
            break;
 
        /* Slow-decay reverse: IN1 static HIGH, IN2 PWM (PWM low = drive) */
        case REVERSE:
            T32A0_SetOutCRA1(T32A_OUTPUT_HIGH);      /* IN1 = static HIGH */
            T32A0_SetOutCRB1(T32A_OUTPUT_PPG);       /* IN2 = PWM         */
            T32A0_SetTimerA0(0U);
            T32A0_SetTimerB0(duty);
            break;
 
        /* IN1=HIGH, IN2=HIGH -> both outputs low -> motor shorted */
        case BRAKE:
            T32A0_SetOutCRA1(T32A_OUTPUT_HIGH);
            T32A0_SetOutCRB1(T32A_OUTPUT_HIGH);
            T32A0_SetTimerA0(0U);
            T32A0_SetTimerB0(0U);
            break;
 
        /* IN1=LOW, IN2=LOW -> Hi-Z -> standby */
        case STOP:
            T32A0_SetOutCRA1(T32A_OUTPUT_LOW);
            T32A0_SetOutCRB1(T32A_OUTPUT_LOW);
            T32A0_SetTimerA0(0U);
            T32A0_SetTimerB0(0U);
            break;
    }
 
    motor_left_dir = dir;
    T32A0_Start();
}
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

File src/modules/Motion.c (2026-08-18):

/**
 * @file        Motion.c
 * @brief       Speed control for the Micromouse
 * @version     V1.1.0
 * @date        14-08-2026
 *
 * @details
 *   Bridges Encoder feedback, PID control, and Motor output.
 *   Runs the inner speed loop at 1 kHz.
 *
 *
 * @note
 *   File structure and Doxygen formatting assisted by AI.
 *
 * Copyright (c) [Kevin Le] 2026
 */

#include "Motion.h"
#include "Encoder.h"
#include "PID.h"
#include "Motor.h"


/* ==========================================================================
 *   Private Data
 * ========================================================================== */

static pid_t pid_left;
static pid_t pid_right;

static float target_left = 0.0f;
static float target_right = 0.0f;

static float output_left  = 0.0f;
static float output_right = 0.0f;

/* Last commanded direction per motor, held through the output deadzone. */
static motor_dir_t last_dir[2] = { FORWARD, FORWARD };

/* ==========================================================================
 *   Private Helpers
 * ========================================================================== */

/**
 * @brief  Convert PID output to motor direction and duty.
 * @param  motor   MOTOR_LEFT or MOTOR_RIGHT
 * @param  output  PID output in range [-100.0, +100.0]
 * @details
 *   Sign selects direction, magnitude becomes duty percent. Output is
 *   in the robot frame; no mounting sign is applied here.
 *
 *   Under the slow-decay drive scheme in Motor.c, a direction commanded
 *   at 0 % duty holds the motor in BRAKE rather than coasting.
 *
 *   Outputs whose magnitude falls inside MOTION_DEADZONE retain the previous
 *   direction at zero duty. Motor.c treats any direction change as stop,
 *   reconfigure, restart of the timer channel, so an output dithering either
 *   side of zero would otherwise tear down and restart the PWM peripheral at
 *   up to 1 kHz. The band matches the range that already rounds to zero duty,
 *   so no commandable speed is lost.
 */
static void Motion_ApplyOutput(motor_t motor, float output)
{
    motor_dir_t dir;
    float       magnitude;

    if (output > MOTION_DEADZONE)
    {
        dir       = FORWARD;
        magnitude = output;
    }
    else if (output < -MOTION_DEADZONE)
    {
        dir       = REVERSE;
        magnitude = -output;
    }
    else
    {
        dir       = last_dir[motor];
        magnitude = 0.0f;
    }

    last_dir[motor] = dir;

    Motor_Set(motor, dir, (uint8_t)(magnitude + MOTION_ROUND_OFFSET));
}

/* ==========================================================================
 *   Initialization
 * ========================================================================== */

/**
 * @brief  Initialize PID controllers & Motor related modules.
 * @note   Encoder are Motor must be initialized first.
 */
void Motion_Init(void)
{
    Encoder_Init();
    Motor_Init();

    /* PID Creating for motor control for moving forward/backward*/
    PID_Create(&pid_left);
    PID_Create(&pid_right);

    target_left = 0.0f;
    target_right = 0.0f;

}

/* ==========================================================================
 *   Motion Update (1 kHz)
 * ========================================================================== */

/**
 * @brief  Run one PID control tick.
 * @details
 *   1. Read wheel speeds from Encoder
 *   2. Compute error = target - actual
 *   3. Run PID
 *   4. Apply to motors
 *
 */
void Motion_Update(void)
{
    float actual_left, actual_right;
    float error_left, error_right;

    if ((target_left == 0.0f) && (target_right == 0.0f))
    {
        PID_Reset(&pid_left);
        PID_Reset(&pid_right);

        output_left  = 0.0f;
        output_right = 0.0f;

        Motion_ApplyOutput(MOTOR_LEFT,  0.0f);
        Motion_ApplyOutput(MOTOR_RIGHT, 0.0f);
        return;
    }

    actual_left  = (float)Encoder_GetSpeed_CPS(MOTOR_LEFT);
    actual_right = (float)Encoder_GetSpeed_CPS(MOTOR_RIGHT);

    error_left = CalculateError(target_left, actual_left);
    error_right = CalculateError(target_right, actual_right);

    output_left  = PID_Update(&pid_left,  error_left);
    output_right = PID_Update(&pid_right, error_right);

    Motion_ApplyOutput(MOTOR_LEFT,  (float)MOTOR_SIGN_LEFT  * output_left);
    Motion_ApplyOutput(MOTOR_RIGHT, (float)MOTOR_SIGN_RIGHT * output_right);
}

/* ==========================================================================
 *   Speed Commands
 * ========================================================================== */

/**
 * @brief  Set target wheel speeds.
 * @param  left_cps   Target left speed (CPS). Positive = forward.
 * @param  right_cps  Target right speed (CPS). Positive = forward.
 * @note   Called every tick by Navigator during a drive, so this path
 *         must not carry per-call PID state resets.
 */
void Motion_SetSpeed(float left_cps, float right_cps)
{
    target_left  = left_cps;
    target_right = right_cps;
}

/**
 * @brief  Sets both wheels forward at the same speed.
 * @param  speed_cps  Target speed (CPS).
 */
void Motion_SetMoveForwardSpeed(float speed_cps)
{
    Motion_SetSpeed(speed_cps, speed_cps);
}

/**
 * @brief  Sets both wheels backward at the same speed.
 * @param  speed_cps  Target speed (CPS).
 */
void Motion_SetMoveBackwardSpeed(float speed_cps)
{
    Motion_SetSpeed(-speed_cps, -speed_cps);
}

/**
 * @brief  Sets Turn left (CCW) Speed.
 * @param  speed_cps  Wheel speed during turn (CPS).
 */
void Motion_SetTurnLeftSpeed(float speed_cps)
{
    Motion_SetSpeed(-speed_cps, speed_cps);
}

/**
 * @brief  Sets Turn right (CW) Speed
 * @param  speed_cps  Wheel speed during turn (CPS).
 */
void Motion_SetTurnRightSpeed(float speed_cps)
{
    Motion_SetSpeed(speed_cps, -speed_cps);
}

/**
 * @brief  Stop immediately.
 * @details  Resets PID, clears targets, applies motor brake.
 */
void Motion_Stop(void)
{
    PID_Reset(&pid_left);
    PID_Reset(&pid_right);
    target_left = 0.0f;
    target_right = 0.0f;
    output_left  = 0.0f;
    output_right = 0.0f;

    Motor_Set(MOTOR_LEFT, STOP, 0U);
    Motor_Set(MOTOR_RIGHT, STOP, 0U);
}

/* ==========================================================================
 *   Accessors/Getters
 * ========================================================================== */

/**
 * @brief  Get target (Set Point - SP)
 * @details  
 */
float Motion_GetTarget(motor_t motor)
{
    if (motor == MOTOR_LEFT)  return target_left;
    if (motor == MOTOR_RIGHT) return target_right;
    return 0.0f;
}

/**
 * @brief  Get manipulated variable(MV) output
 * @details  
 */
float Motion_GetOutput(motor_t motor)
{
    if (motor == MOTOR_LEFT)  return output_left;
    if (motor == MOTOR_RIGHT) return output_right;
    return 0.0f;
}

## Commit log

2026-07-28 Evidence (#5)
    * Will change Navigation and move logic. WIP
    * Added: Steering correction controls in Nav
    * Changed: PID Deriv to negate, and added Error calculations for forward motion
    * Revereted: PID
    * Optimized: IR sensor and changed PID comment
    * Implemented UART output for Matlab
    * Fixed UART and motion CPS speed
    * Added: Evidence template for logging. Reworked PID UART Matlab logging
    * Added Documentation paths for Intro Readme.md
    * Added Debugging tool pictures
    * [Fixed] Image README in pcb
    * Fixed it this time
    * [Reformatted] README.md main
    * IMPORTANT: CHANGED PCB AND FIXED TIMER32A DRIVER FOR MOTOR CONTROLS.
    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
    [BOM.csv, TMPM4KNF10AFG.kicad_pcb, TMPM4KNF10AFG.kicad_sch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]
2026-07-31 Tuned: PID Controller for smooth motor controls Fixed: Comment related issues Fixed: Encoder module for UART to Matlab communication and data gathering tests
    [Encoder.c, ModuleTest.c, Motor.c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]
2026-08-08 Added: MATLAB graphs and txt output for PID graphing
2026-08-08 Debugged: PCB design for Toshiba's MOSFET.
2026-08-11 Updated: ADC drivers
2026-08-18 Added: Error & Gain Control loop for Wall Sensing w/ IR
    [IrSensor.c, ModuleTest.c, Motion.c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]
2026-08-19 Updated: Documentation regarding setup and some generally formatting
    [LiPo_103450_2000mAh.SLDPRT, LiPo_103450_2000mAh.STEP, micro-metal-gearmotor-bracket.step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]
2026-08-19 Updated: Kicad libraries for Schematic and PCB
    [TMPM4KNF10AFG.kicad_pcb, TMPM4KNF10AFG.kicad_sch]
2026-08-19 Organized: Kicad project directory
    [TMPM4KNF10AFG.kicad_pcb, TMPM4KNF10AFG.kicad_sch]
2026-08-19 Updated: src/README.md for clarity and structure. Nav.c updated for FrontWall error detection for 180mm cell alignment
    [Navigator.c]
2026-09-02 Final step (#7)
    * Added: Doxygen html file for reading and documentation
    * Updated: src/README.MD sturcture and updated TestModule to see interopolated values
    * Fixed .md Call graph directory naming
    * Edited: for cpp in header files
    * Added Python simulation (WIP)
    * Removed Cmake plan
    * Removed the Cmake related files
    * Update keil project file
    * Added: More IR sensor distances for interpolation
    * Updated: local Vendor provided folder file PATH to be used for .uvprojx
    * Removed unnecessary file in keil/
    * Updated: Matlab telemetry
    * Updated: Simulation python files
    * Changed Motion module CPS speed for negative and positive motions
    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
    [chassis.stl]

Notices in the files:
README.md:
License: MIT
